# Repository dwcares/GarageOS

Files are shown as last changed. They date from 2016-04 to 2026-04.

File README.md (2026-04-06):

# GarageOS: Building a Smart Garage

A few months ago, the garage door opener motor at my house failed. I don't blame it -- after decades of dutifully opening and closing its 160 lb door on command, perhaps it was time for a rest. Also this old garage door opener didn't have the benifits of modern technology, like secure radio codes, advanced drive systems and of course, internet connectivity.

Walking through the aisle of a suburban Home Depot, I was amazed to see how many of the garage door openers sold there provided some sort of app to control and get notifications about the door. Those features seem cool, but besides a hefty $200 price premium, I don't just want a smart garage door opener, I want a complete smart garage. So, I bought the cheapest opener for $60 bucks and set off to build a smart garage myself: GarageOS.

## Scope it out
Given my background in building products, for most projects that I take on, even the fun ones, I go through a quick process of planning. Really, what's the pain that I'm trying to solve, to make my life better...not just add technology for technology sake (even though there's some of that too).

### Problems worth solving
1. When I'm heading out on a walk or a bike ride, I always go out the garage since that's the best way to get to town, and it's where all the wagons, strollers and bikes are stored. This means brining a garage door remote on every walk, if I forget it, I'm essentially locked out. I wish I always had a garage door remote with me.
2. When I'm halfway across the country on a vacation, I always have that pit in my stomach -- did I leave the garage door open? I wish I could just know, even if I'm in a different time zone.
3. When I pull into the garage with the car, space is at a premium. If I don't pull to close enough, the garage door won't close or I won't be able to get the trunk open, if I pull to close, I wont be able to walk pass the car. I wish I could just know the sweet spot of when I'm parked correctly.
4. When I'm at work, it would be great if I knew my wife's car was home yet, or if she's still on her way.

### Most important to me
Given these problems, let's decide on a few capabilities worth building in our GarageOS. If I build these capabilities, I'll solve most of my major problems. Also, besides the new capabilities that I'm adding to my garage, I have some requirements that make are essential to making this something that is actually helping me, not making my life worse.
* Open and close the door
* Know if the door is open, and for how long
* Know if a car is parked
* Know if I'm parked correctly
* Don't interfere with the safety or reliablilty of the garage
* Be as reliable as a physical garage door opener

### Other cool stuff
In the future, we might want to add some more cool stuff too, but for now we'll park these for future consideration. 
* Know temperature and humidity
* More security features and cameras
* Security alerts and texts
* Log arrival/departure times
* Speech command and control, conversational AI (what could go wrong?)

Open the pod bay doors

## The Hardware Build

### Things used in the project
* [Particle Photon](https://store.particle.io/collections/photon)
* [Particle Relay Shield](https://store.particle.io/collections/shields-and-kits)
* [5mm Common Cathode RGB LED](http://www.amazon.com/microtivity-IL612-Diffused-Controllable-Common/dp/B006S21SQO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)
* [5 dB Antenna](http://www.amazon.com/Wi-fi-Antenna-RP-SMA-Antennas-Cables/dp/B00A4I3AGE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)
* [Magnetic Reed Switch](http://www.amazon.com/Directed-Electronics-8601-Magnetic-Switch/dp/B0009SUF08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)
* [Strong Disc Magnet](http://www.amazon.com/Industrial-Grade-10E794-Magnet-Ceramic/dp/B007OXE56G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)
* [Hc-SR04 Ultrasonic ping sensor](http://www.amazon.com/Mihappy-Ultrasonic-Distance-Measuring-Transducer/dp/B00IJWZTI4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)

### Step 1: Opening and closing the doors

*The Garage Door Switch*

So the first and most obvious thing for me to build was to open and close the doors. This way I could use a website or my phone to open the door when I'm out on a walk. I was nervous about figuring out how to actually toggle the door open and closed. But then I took the switch off the wall, connected the two wires and the door came to life and travelled down the track. No magic in this wall switch, it just completes the circuit like any switch. Then I just needed to figure out how to do it from the the internets.

*Relay all the things*

 It turns out, doing this is amazingly easy with a Particle Photon and a relay. A relay is like a digitally controlled switch. It's just as easy to use as turning an LED on and off (the 'hello world' of IoT Projects) but instead of turning a light on, it changes the world around you by switching potentially higher voltage stuff like Christmas lights, rocket launch circuits, or in this case a garage door. To control it from the internet, all I did was follow the Particle: [Control an LED from the 'nets](https://docs.particle.io/guide/getting-started/examples/photon/#control-leds-over-the-39-net) sample and replace LED in the circuit with the relay. Sweet. I hooked the other side of the relay up to the door switch on the wall, and I was in business!
 
### Step 2: Reading the Garage Door State
 
 *But, is the door open tho?*
 
 Something I quickly figured out after demoing that I could open my garage door from across the country, is that I had created a new problem for myself. If I forgot how many times I hit the button, or accidently opened the door, I had no idea if the door was open or closed, potentially leaving the garage and all of it's cluttered goodies vulnerable for theft.
 
 *Magnetic reed switch*
 
 After a tiny bit of reseach I found a Magnetic Reed Switch. It's basically, what you see on those window security systems. One side is a basic magnet, and the other side is a switch that closes when another magnet is nearby. For the garage door, I put a heavy duty magnet on the door, and a mounted the switch on the wall so when the door was closed, the magnet would line up with the switch. When the door was open, the switch would be open. Then it was just a matter of running a bunch of wires through the rafters from the door to the Photon, mounted by the wall.
 
### Step 3: Parking distance
The next thing we want to be able to do is to read the parking distance of the car the car parked in the garage. Essentially, how far is the car parked from the wall? Then we want to indicate to the driver of the car with some sort of visual status that they've parked correctly, or parked too close.

*Ultrasonic ping sensor* 

In order to measure the parking distance, I ended up using an ultrasonic ping sensor. It's basically a microphone and a speaker in one. The microphone is listening for a specific tone, and the speaker is emitting that tone at a specified interval. Then in the code, I was measure how long it takes for the tone to to bounce back from the car as it approaches the wall. With the speed of sound a constant, I could calcuate this is centemeters. 

I could then use this measured distance value to report the status back to the driver. In my case, I was looking for a sweet spot of 50 inches. If it was any less than 50 inches, it was too close, or any greater than 60 inches, and the car is not pulled in far enough. I used these values to decide what color to change the led to. 

### Hardware overview

Now that the hardware is built and in place, now it's just a matter of writing the firmware to behave the way we want it to, and write a mobile app to wrap it all up. 

### Wiring Diagram
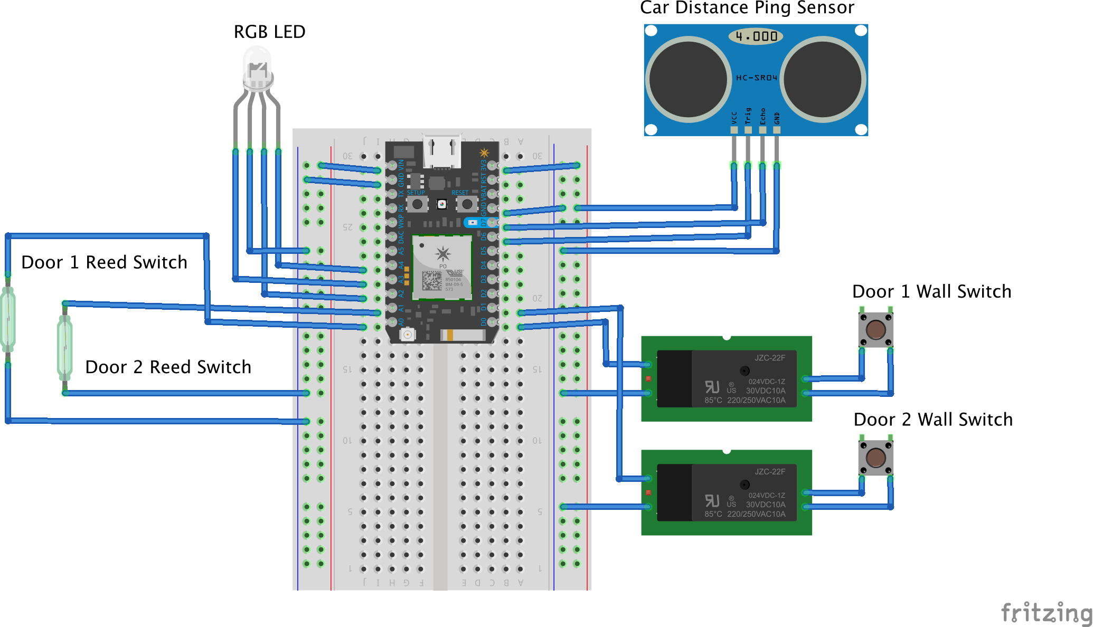
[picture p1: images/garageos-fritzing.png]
Wiring diagram


## The Firmware

The Particle Photon runs a continuous loop that monitors sensors and publishes state to the Particle Cloud.

### Pin assignments

| Pin | Function |
|-----|---|
| D0 | Small door relay |
| D1 | Big door relay |
| A0 | Small door magnetic reed switch |
| A1 | Big door magnetic reed switch |
| A2 | Parking LED (Yellow) |
| A3 | Parking LED (Magenta) |
| A4 | Parking LED (Cyan) |
| D6 | Ultrasonic sensor trigger |
| D7 | Ultrasonic sensor echo |

### Cloud variables

| Variable | Type | Description |
|---|---|---|
| `door1Status` | int | Small door: 0 = closed, 1 = open |
| `door2Status` | int | Big door: 0 = closed, 1 = open |
| `car1Distance` | int | Parking distance in inches |
| `car1Status` | int | 0 = not parked, 1 = parked, 2 = too close |
| `wifiStrength` | int | WiFi RSSI in dBm |

### Cloud functions

| Function | Argument | Description |
|---|---|---|
| `toggleDoor` | `r1` or `r2` | Pulses relay for 500ms to toggle the door |

### Sensor smoothing

Both door sensors and the parking sensor use statistical smoothing (100-sample windows) to filter noise. The parking sensor also uses standard deviation to reject outlier readings.

### Heartbeat

The firmware publishes a JSON heartbeat event every 60 seconds (or immediately on state change). This includes all sensor values, door open durations, and uptime. The iOS and watchOS apps subscribe to these events for real-time updates.

### SMS alerts

A Particle webhook (`firmware/webhook.json`) can be configured with Twilio credentials to send SMS alerts when a door has been open for too long.

## The Software Build

### iOS App

The iPhone app connects to the Particle Cloud via the Particle iOS SDK (CocoaPods) and provides:

* **Door control** -- Press the Small or Big door button to toggle
* **Door status** -- Visual indicators show open/closed state with open duration timers
* **Parking distance** -- Shows car distance in inches with a progress bar
* **Signal strength** -- Displays WiFi RSSI and last update time
* **Real-time updates** -- Subscribes to heartbeat and door-status-change events via Particle Cloud SSE

### watchOS App

The Apple Watch companion app is a standalone SwiftUI app that talks directly to the Particle Cloud REST API -- no iPhone required. It works independently over WiFi or cellular.

* **Crown dial to trigger** -- Rotate the Digital Crown to fill a ringto toggle the door. This intentional gesture prevents accidental triggers.
* **Haptic feedback** -- Subtle clicks and satisfying success haptic at 100%
* **Door status** -- Full blue ring = closed, empty ring = open. Polls every 10 seconds.
* **Two pages** -- Swipe horizontally between Small Door and Big Door

## Project Structure

```
garageos/
  firmware/
    garageos.ino          # Main Particle Photon firmware
    statistic.h/.cpp      # Sensor smoothing library
    webhook.json          # Twilio SMS alert webhook config
  iOS/
    GarageOS/             # iPhone app (UIKit + Particle SDK)
      AppDelegate.swift
      ViewController.swift
      GarageClient.swift  # Particle Cloud singleton
      Secrets.swift       # Credentials (gitignored)
    GarageOSWatch/        # Watch app (SwiftUI + REST API)
      GarageOSWatchApp.swift
      DoorDialView.swift  # Crown dial UI
      GarageManager.swift # Status polling + door toggle
      ParticleAPI.swift   # Direct Particle Cloud REST client
    Podfile               # CocoaPods (iOS app only)
  images/
    garageos-fritzing.png # Wiring diagram
    garageos-fritzing.fzz # Editable Fritzing source
```

## Setup

### Prerequisites

* Xcode 15+
* CocoaPods (`brew install cocoapods`)
* A Particle Photon with the firmware flashed
* A Particle Cloud account

### iOS & watchOS apps

1. Clone the repo
2. Create `iOS/GarageOS/Secrets.swift` with your credentials:
   ```swift
   public class Secrets {
       static let particleUser: String = "your@email.com"
       static let particlePassword: String = "your-password"
       static let particleDeviceID: String = "your-device-id"
   }
   ```
3. Install pods:
   ```
   cd iOS
   pod install
   ```
4. Open `iOS/GarageOS.xcworkspace` in Xcode
5. Build and run the **GarageOS** scheme for iPhone
6. Build and run the **GarageOSWatch** scheme for Apple Watch

### Firmware

1. Set up your Particle Photon on your WiFi network via the [Particle app](https://docs.particle.io/getting-started/getting-started/photon/)
2. Flash `firmware/garageos.ino` via the [Particle Web IDE](https://build.particle.io) or Particle CLI
3. Wire up the hardware per the [wiring diagram](images/garageos-fritzing.png)

## License

[MIT](LICENSE)

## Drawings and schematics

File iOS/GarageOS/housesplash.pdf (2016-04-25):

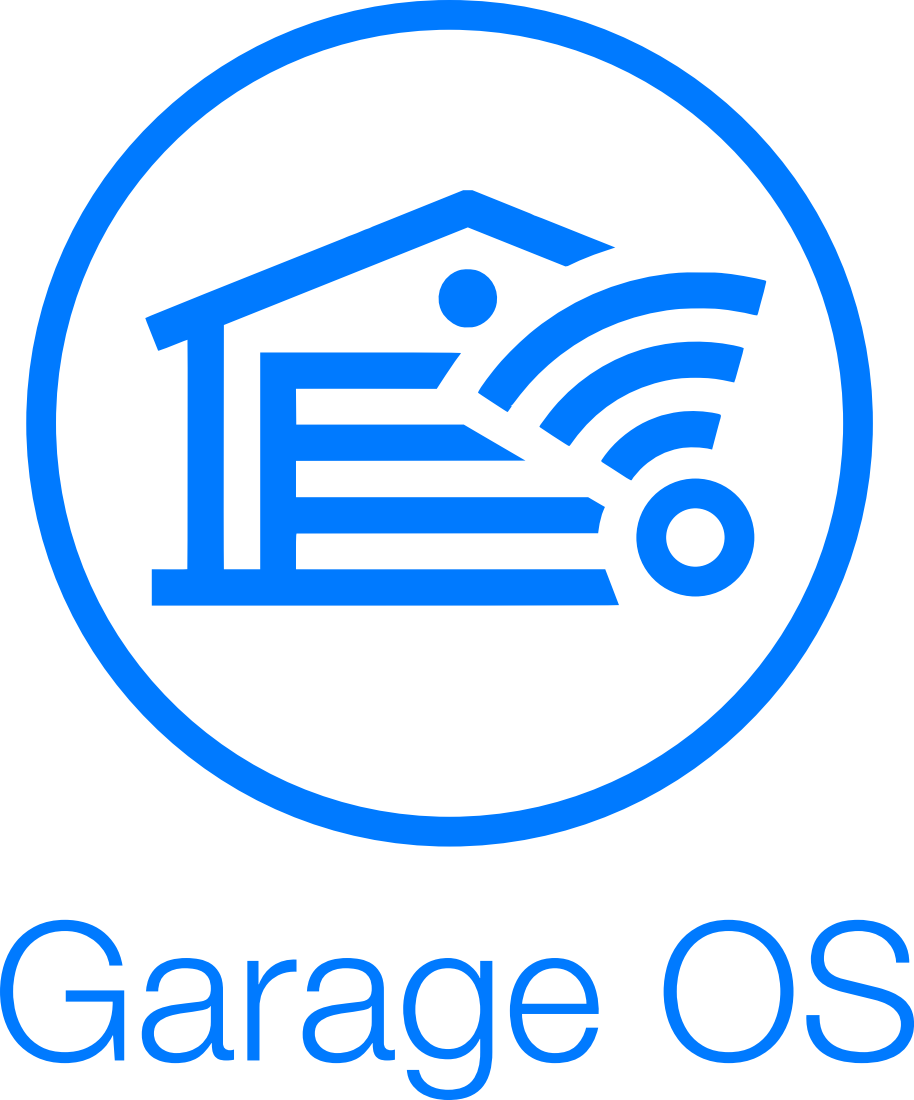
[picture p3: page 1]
Garage OS

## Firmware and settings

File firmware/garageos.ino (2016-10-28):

#include "Statistic.h"

// Photon Pins
int door1Relay = D0; // Small door
int door2Relay = D1; // Big Door

int door1Sensor = A0;
int door2Sensor = A1;

int car1YellowLED = A2;
int car1MagentaLED = A3;
int car1CyanLED = A4;

int car1SensorTrig = D6;
int car1SensorEcho = D7;

// Particle Cloud variables
int wifiStrength;

int door1Status = 0;
int door2Status = 0;

int door1LastOpenTime = 0;
int door2LastOpenTime = 0;
int door1OpenDuration = 0;
int door2OpenDuration = 0;

int car1ParkingStatus = 0;
int car2ParkingStatus = 0;

int car1Distance = 0;
int car2Distance = 0;

int const CAR_STATUS_NOTPARKED = 0;
int const CAR_STATUS_PARKED = 1;
int const CAR_STATUS_PARKEDCLOSE = 2;
int const CAR_STATUS_INVALID = -1;

int const DOOR_STATUS_CLOSED = 0;
int const DOOR_STATUS_OPEN = 1;

// Parking Sensor Smoothing
Statistic car1SensorStats; 
int const MAX_PARKING_TICKS = 100;
int const MAX_STDEV = 10;
int const PARKING_SENSOR_DELAY_MS = 10;
static bool sensorInit = false;

// Door Sensor Analog Smoothing
Statistic door1SensorStats; 
Statistic door2SensorStats; 

int const MIN_DOOR_THRESHOLD = 250;
int const MAX_DOOR1_TICKS = 100; 
int const MAX_DOOR2_TICKS = 100; 

// Server health
bool needsPublish = true;
int lastPublish = 0;
int const MIN_PUBLISH_DELTA = 1000;
int const MAX_PUBLISH_DELTA = 60000;

STARTUP(WiFi.selectAntenna(ANT_EXTERNAL));

void setup()
{
    pinMode(door1Relay, OUTPUT); 
    pinMode(door2Relay, OUTPUT);

    pinMode(car1YellowLED, OUTPUT);
    pinMode(car1MagentaLED, OUTPUT);
    pinMode(car1CyanLED, OUTPUT);
    
    Particle.variable("door1Status", &door1Status, INT);
    Particle.variable("door2Status", &door2Status, INT);
    Particle.variable("car1Distance", &car1Distance, INT);
    Particle.variable("car2Distance", &car2Distance, INT);
    Particle.variable("car1Status", &car1ParkingStatus, INT);
    Particle.variable("car2Status", &car2ParkingStatus, INT);
    Particle.variable("wifiStrength", &wifiStrength, INT);

    Particle.function("toggleDoor", toggleDoor);
    
    door1SensorStats.clear();
    door2SensorStats.clear();
    car1SensorStats.clear();
    
    digitalWrite(car1YellowLED, LOW);
    digitalWrite(car1MagentaLED, LOW);
    digitalWrite(car1CyanLED, LOW);
}

void loop()
{
    heartbeat();
    
    monitorCarStatusChange();
    monitorDoorStatusChange();

}

////////////////////////////////////
////////// PARKING STATUS ////////// 
////////////////////////////////////

void monitorCarStatusChange() {
  
  int tempParkingStatus = car1ParkingStatus;
   
  updateCarStatus();

  if (tempParkingStatus != car1ParkingStatus) {
      needsPublish  = true;
  }
}

bool updateCarStatus() {

    int car1DistanceRAW = measureInches(car1SensorTrig, car1SensorEcho, PARKING_SENSOR_DELAY_MS);
    
    car1SensorStats.add(car1DistanceRAW);
    
    updateCarStatusLED(getParkingStatusFromDistance(car1DistanceRAW));
    
   if (car1SensorStats.count() >= MAX_PARKING_TICKS) {
      if (car1SensorStats.pop_stdev() >= MAX_STDEV) {
          car1Distance = max(car1SensorStats.maximum(), 100);
      } 
      else {
          car1Distance = (int) car1SensorStats.average();
      }
          
      car1ParkingStatus = getParkingStatusFromDistance(car1Distance);
      car1SensorStats.clear();
    }
}

int measureInches(pin_t trig_pin, pin_t echo_pin, uint32_t wait)
{
    uint32_t duration, inches, cm;
    if (!sensorInit) {
        pinMode(trig_pin, OUTPUT);
        digitalWriteFast(trig_pin, LOW);
        pinMode(echo_pin, INPUT);
        delay(50);
        sensorInit = true;
    }

    digitalWriteFast(trig_pin, HIGH);
    delayMicroseconds(wait);
    digitalWriteFast(trig_pin, LOW);
  
    duration = pulseIn(echo_pin, HIGH);

    inches = duration / 74 / 2;
    cm = duration / 29 / 2;
    
    return inches;
}

int getParkingStatusFromDistance(int distance) {
    
    int parkingStatus = CAR_STATUS_INVALID;
    
   if (car1Distance > 60) {
       parkingStatus = CAR_STATUS_NOTPARKED;
    } else if (car1Distance > 40) {
       parkingStatus = CAR_STATUS_PARKED;
    } else if (car1Distance <= 40) {
        parkingStatus = CAR_STATUS_PARKEDCLOSE;
    }
    
    return parkingStatus;
}

void updateCarStatusLED(int carStatus) {
    
    // Only reflect LED parking status when the door is open
    if (door2Status == DOOR_STATUS_CLOSED) {
        digitalWrite(car1YellowLED, HIGH);
        digitalWrite(car1MagentaLED, HIGH);
        digitalWrite(car1CyanLED, HIGH);
    } else {
        switch (carStatus)
        {
          case CAR_STATUS_NOTPARKED:
          
            // YELLOW
            digitalWriteFast(car1YellowLED, HIGH); 
            digitalWriteFast(car1MagentaLED, LOW); 
            digitalWriteFast(car1CyanLED, LOW); 
            break;
            
          case CAR_STATUS_PARKED:
            
            // GREEN
            digitalWriteFast(car1YellowLED, HIGH);
            digitalWriteFast(car1MagentaLED, LOW); 
            digitalWriteFast(car1CyanLED, HIGH);
            break;
            
          case CAR_STATUS_PARKEDCLOSE:
          
            // RED
            digitalWriteFast(car1YellowLED, HIGH);
            digitalWriteFast(car1MagentaLED, HIGH);
            digitalWriteFast(car1CyanLED, LOW);
            break;
            
          default:
          
            // WHITE
            digitalWrite(car1YellowLED, LOW);
            digitalWrite(car1MagentaLED, LOW);
            digitalWrite(car1CyanLED, LOW);
        }
    }
        
}

////////////////////////////////////
/////////// DOOR STATUS //////////// 
////////////////////////////////////

void monitorDoorStatusChange() {
    
    int tempDoor1Status = door1Status;
    int tempDoor2Status = door2Status;
    
    updateDoorStatus();
 
    
    if (tempDoor1Status != door1Status) {    
        needsPublish = true;
        
        door1LastOpenTime = (door1Status == DOOR_STATUS_OPEN) ? millis() : 0;
        //publish("door-status-change/door1", door1Status);
    }
    
    if (tempDoor2Status != door2Status) {
        needsPublish = true;
        
        door2LastOpenTime = (door2Status == DOOR_STATUS_OPEN) ? millis() : 0;

       // publish("door-status-change/door2", door2Status);
    }
    
     updateOpenDuration();
}

void updateDoorStatus()
{
    // Update Door 1 Status
    int door1SensorRaw = analogRead(door1Sensor);
    door1SensorStats.add(door1SensorRaw);
    
    if (door1SensorStats.count() > MAX_DOOR1_TICKS) {
        int door1SensorValue = door1SensorStats.average();
        
        door1Status = door1SensorValue > MIN_DOOR_THRESHOLD ? DOOR_STATUS_OPEN : DOOR_STATUS_CLOSED;
        
        door1SensorStats.clear();
    }

    
    // Update Door 2 Status
    int door2SensorRaw = analogRead(door2Sensor);
    door2SensorStats.add(door2SensorRaw);
    
    if (door2SensorStats.count() > MAX_DOOR2_TICKS) {
        int door2SensorValue = door2SensorStats.average();
        
        door2Status = door2SensorValue > MIN_DOOR_THRESHOLD ? DOOR_STATUS_OPEN : DOOR_STATUS_CLOSED;
        
        door2SensorStats.clear();
    }
}

void updateOpenDuration() {
    door1OpenDuration = (door1Status == DOOR_STATUS_OPEN) ? millis() - door1LastOpenTime : 0;
    door2OpenDuration = (door2Status == DOOR_STATUS_OPEN) ? millis() - door2LastOpenTime : 0;
}

void heartbeat() 
{
    unsigned long now = millis();
    int publishDelta = now - lastPublish;
    
    if (publishDelta > MAX_PUBLISH_DELTA || (publishDelta > MIN_PUBLISH_DELTA && needsPublish )) {
        wifiStrength = WiFi.RSSI();

        String publishString = String::format("{\"uptime\":\"%d\",\"wifiStrength\":%d,\"car1Distance\":%d,\"car1ParkingStatus\":%d,\"door1Status\":%d,\"door2Status\":%d,\"door1OpenDuration\":%d,\"door2OpenDuration\":%d}",now,wifiStrength,car1Distance,car1ParkingStatus,door1Status,door2Status,door1OpenDuration, door2OpenDuration);
        publish("heartbeat", publishString);
    }
}

void publish(String eventName, int message) {
    publish(eventName, String(message)); //.c_str()
}

void publish(String eventName, String message) {
     Particle.publish(eventName, message);
     lastPublish = millis();
     needsPublish = false;
}

int toggleDoor(String command)
{
  int doorNumber = command.charAt(1) - '0';

  if (doorNumber < 1 || doorNumber > 2) return -1;
  
  publish("door", command);
 
  digitalWrite(doorNumber-1, 1);
  delay(500);
  digitalWrite(doorNumber-1, 0);

  return 1;
}

int requestUpdate(String command)
{
  needsPublish = true;
  return 1;
}

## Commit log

2016-07-29 add schematic
    [garageos-fritzing.fzz]
2016-10-28 fix no-msband crash, 60s refresh
    [garageos.ino]
2016-11-06 blog text draft
    [garageos-fritzing.fzz]
2026-04-06 Modernize iOS app and add standalone SwiftUI watchOS app
    - Update iOS app from Swift 4 to Swift 5, iOS 16+ deployment target
    - Remove dead dependencies (HockeySDK, Azure Notification Hubs, ParticleSwift)
    - Replace legacy WatchKit 2 targets with modern single-target SwiftUI watch app
    - Watch app talks directly to Particle Cloud REST API (no iPhone dependency)
    - Crown dial UX: spin to fill ring, haptic feedback at 50%/75%/100%, triggers door toggle
    - Ring decay with fade animation after 1s idle
    - Live door status polling every 10s with optimistic state updates
    - Rename car label from BMW X3 to Rivian R1S
    - Add WatchConnectivity support to iOS AppDelegate for future use
    - Track door open/closed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
2026-04-06 Clean up iOS app: remove WatchConnectivity, fix door buttons, reduce log noise
    - Remove WatchConnectivity (watch talks directly to Particle REST API)
    - Replace 3D Touch deep press with long press gesture (3D Touch removed on modern iPhones)
    - Add haptic feedback on door toggle with pre-warmed engine
    - Delete DeepPressGestureRecognizer and DeepPressableButton (unused)
    - Add SF Symbol WiFi strength indicator
    - Clean up verbose logging, keep concise heartbeat/toggle/status logs
